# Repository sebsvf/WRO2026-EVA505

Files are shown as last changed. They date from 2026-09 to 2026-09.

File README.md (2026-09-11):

<!--
EVA505 · README principal.
Los cuadros de fotografía ya se renderizan: cada uno utiliza un SVG local.
Para incorporar una foto, cambia únicamente el atributo src del cuadro.
Las rutas propuestas y la lista de imágenes están en docs/IMAGENES_README.md.
-->

<p align="center">
  EVA505 · WRO Future Engineers 2026 · Mecánica R08, visión y control autónomo
</p>

<h1 align="center">EVA505 · Future Engineers 2026</h1>

<p align="center">
  <strong>Diseño mecánico, visión artificial y control embebido en un mismo vehículo.</strong><br>
  Equipo EVA505 · UTEC / IEEE RAS UTEC
</p>

<p align="center">
  <a href="#proyecto">Proyecto</a> ·
  <a href="#arquitectura">Arquitectura</a> ·
  <a href="#mecanica">Mecánica</a> ·
  <a href="#electronica">Electrónica</a> ·
  <a href="#software">Software</a> ·
  <a href="#ejecucion">Ejecución</a> ·
  <a href="#validacion">Validación</a> ·
  <a href="#repositorio">Archivos</a>
</p>

<table>
  <tr>
    <td width="33%" align="center"><strong>R08</strong><br><sub>Revisión mecánica · 4 diseños, 5 piezas</sub></td>
    <td width="34%" align="center"><strong>Raspberry Pi 5 + ESP32</strong><br><sub>Visión, navegación y control de actuadores</sub></td>
    <td width="33%" align="center"><strong>Sin encoder</strong><br><sub>Tracción por PWM · dirección Ackermann</sub></td>
  </tr>
</table>

---

## 01 · El proyecto

**EVA505 es un vehículo autónomo desarrollado para WRO Future Engineers 2026.** Integra un chasis comercial de cuatro ruedas, dirección delantera Ackermann, tracción trasera y soportes diseñados para impresión 3D. La cámara aporta la información visual de la pista; la Raspberry Pi interpreta esa información y el ESP32 ejecuta las órdenes de dirección y tracción.

El repositorio reúne el diseño mecánico, el esquema eléctrico, el firmware, los algoritmos de percepción y navegación, las herramientas de diagnóstico y la evidencia de validación. Su organización permite seguir el recorrido completo desde una pieza CAD hasta una orden enviada al motor.

| Área | Solución de EVA505 |
| :--- | :--- |
| Estructura | Chasis comercial con dos plataformas, portal frontal y rieles de batería R08. |
| Movimiento | Motor DC GA25 para tracción trasera y servo MG996R para dirección. |
| Percepción | Cámara, Picamera2 y OpenCV; análisis de paredes, pilares y marcadores de suelo. |
| Decisión | Control de dirección PD y máquina de estados en Python. |
| Ejecución | ESP32 con PWM, rampas, pulsador START y vigilancia de comandos. |
| Reproducibilidad | Archivos STEP/STL, configuración YAML, pruebas y registros de resultados. |

> **Estado de la revisión:** software validado en PC y firmware compilado. La calibración del vehículo, la validación eléctrica bajo carga y las tandas completas en pista siguen pendientes de registro. El estacionamiento permanece experimental y desactivado por defecto.

### El vehículo en cuatro vistas

<table>
  <tr>
    <td width="50%" align="center" valign="top">
      <!-- FOTO 01 · src sugerido: v-photos/robot-frontal.jpg -->
      Espacio para la vista frontal de EVA505
      <br><strong>01 · Vista frontal</strong><br>
      <sub>Cámara, dirección y despeje de las ruedas delanteras.</sub>
    </td>
    <td width="50%" align="center" valign="top">
      <!-- FOTO 02 · src sugerido: v-photos/robot-superior.jpg -->
      Espacio para la vista superior de EVA505
      <br><strong>02 · Vista superior</strong><br>
      <sub>Distribución de plataformas, electrónica y batería.</sub>
    </td>
  </tr>
  <tr>
    <td width="50%" align="center" valign="top">
      <!-- FOTO 03 · src sugerido: v-photos/robot-lateral.jpg -->
      Espacio para la vista lateral de EVA505
      <br><strong>03 · Vista lateral</strong><br>
      <sub>Separación entre niveles y posición del portal.</sub>
    </td>
    <td width="50%" align="center" valign="top">
      <!-- FOTO 04 · src sugerido: v-photos/robot-trasera.jpg -->
      Espacio para la vista trasera de EVA505
      <br><strong>04 · Vista trasera</strong><br>
      <sub>Tracción, retención de batería y acceso al montaje.</sub>
    </td>
  </tr>
</table>

## 02 · Arquitectura del sistema

El procesamiento se divide entre dos placas. La **Raspberry Pi 5** trabaja con imágenes y toma decisiones; el **ESP32** mantiene el control de los actuadores y supervisa la vigencia de las órdenes recibidas.

<p align="center">
  Cámara a Raspberry Pi 5; comunicación UART bidireccional con ESP32; ESP32 conectado a START, DRV8871 y servo MG996R
</p>

| Capa | Responsabilidad | Resultado |
| :--- | :--- | :--- |
| Captura | Obtener un fotograma reciente y controlar exposición y balance de blancos. | Imagen BGR y referencia temporal. |
| Percepción | Localizar límites de pista, pilares y marcadores mediante HSV y geometría de imagen. | Error lateral, candidatos y confianza. |
| Navegación | Seleccionar el comportamiento y calcular dirección y potencia. | Una orden conjunta de movimiento. |
| Comunicación | Enviar comandos y comprobar telemetría, secuencias y CRC. | Intercambio UART supervisado. |
| Actuación | Aplicar PWM, límites, rampas y condiciones de arranque. | Tracción y dirección dentro de los límites configurados. |

La comunicación funciona a **115 200 baudios**. La telemetría informa del PWM aplicado, el ángulo ordenado y el estado del controlador; no representa mediciones de velocidad ni de posición del servo.

## 03 · Diseño mecánico R08

### Chasis, dirección y tracción

La base comercial conserva su dirección y transmisión. El **GA25** transmite movimiento al tren trasero, mientras el **MG996R** acciona el mecanismo de dirección delantero.

La geometría **Ackermann** hace que la rueda interior gire más que la exterior durante una curva, aproximando sus trayectorias a un centro de giro común. El radio de giro real depende de la distancia entre ejes, la separación de las ruedas y los ángulos alcanzados por el mecanismo; todavía no se publica un valor medido.

Sobre esta base se distribuyen dos plataformas, un portal de cámara y dos rieles para la batería. La división en subconjuntos facilita desmontar componentes y modificar sus soportes conservando las interfaces de fijación.

### Piezas y archivos de fabricación

Las dimensiones exteriores de esta tabla se comprobaron sobre los **STL presentes en el repositorio**. Son cotas de las piezas, no las dimensiones totales del vehículo.

| Pieza | Cantidad | Envolvente nominal, mm | Función | Descargas |
| :--- | :---: | :--- | :--- | :--- |
| Plataforma inferior | 1 | 104 × 84 × 3,2 | Fijación al chasis, electrónica y soporte del nivel superior. | [STL](Mechanics/EVA505_ELECTRONICS_DECK_UNIVERSAL_R08.stl) · [STEP](Mechanics/EVA505_ELECTRONICS_DECK_UNIVERSAL_R08.step) |
| Plataforma superior | 1 | 104 × 84 × 3,2 | Apoyo del case de la Pi y fijación de módulos inferiores. | [STL](Mechanics/EVA505_PI_CASE_DECK_UNIVERSAL_R08.stl) · [STEP](Mechanics/EVA505_PI_CASE_DECK_UNIVERSAL_R08.step) |
| Portal frontal | 1 | ≈ 40,731 × 79 × 94,643 | Soporte elevado e inclinado de la cámara. | [STL](Mechanics/EVA505_FRONT_CAMERA_PORTAL_R08_PROTOTYPE.stl) · [STEP](Mechanics/EVA505_FRONT_CAMERA_PORTAL_R08_PROTOTYPE.step) |
| Riel de batería | 2 | 72 × 14 × 3,2 por unidad | Apoyo y paso de las correas de retención. | [STL](Mechanics/EVA505_BATTERY_STRAP_RAIL_UNIVERSAL_R08_PRINT_2.stl) · [STEP](Mechanics/EVA505_BATTERY_STRAP_RAIL_UNIVERSAL_R08_PRINT_2.step) |

**Cuatro diseños y cinco piezas impresas.** El sufijo `PRINT_2` indica dos unidades del riel. Los STL se interpretan en milímetros y a escala del 100 %.

<table>
  <tr>
    <td width="50%" align="center" valign="top">
      <a href="Mechanics/EVA505_ELECTRONICS_DECK_UNIVERSAL_R08.png">
        Plano de la plataforma inferior de electrónica R08
      </a>
      <br><strong>Plataforma inferior</strong><br><sub>Interfaz con el chasis y distribución de cargas.</sub>
    </td>
    <td width="50%" align="center" valign="top">
      <a href="Mechanics/EVA505_PI_CASE_DECK_UNIVERSAL_R08.png">
        Plano de la plataforma superior para Raspberry Pi R08
      </a>
      <br><strong>Plataforma superior</strong><br><sub>Case de la Raspberry Pi y segundo nivel.</sub>
    </td>
  </tr>
  <tr>
    <td width="50%" align="center" valign="top">
      <a href="Mechanics/EVA505_FRONT_CAMERA_PORTAL_R08_PROTOTYPE.png">
        Plano del portal frontal de cámara R08
      </a>
      <br><strong>Portal frontal</strong><br><sub>Dos apoyos y placa de cámara inclinada.</sub>
    </td>
    <td width="50%" align="center" valign="top">
      <a href="Mechanics/EVA505_BATTERY_STRAP_RAIL_UNIVERSAL_R08_PRINT_2.png">
        Plano del riel de batería R08
      </a>
      <br><strong>Riel de batería</strong><br><sub>Dos copias con retención mediante correas.</sub>
    </td>
  </tr>
</table>

### Interfaces y decisiones de diseño

Las cotas de interfaces que siguen proceden del aporte mecánico R08 del equipo. Los separadores y suplementos indicados como propuesta corresponden al montaje previsto; su ajuste físico todavía debe registrarse.

| Elemento | Cota o solución nominal | Motivo de diseño |
| :--- | :--- | :--- |
| Unión inferior al chasis | Cuatro ranuras de 16 × 10 mm; centros en patrón de 82 × 64 mm. | Admitir pequeñas diferencias de posición de la base comercial. |
| Reparto del apriete | Arandelas con diámetro exterior de al menos 16 mm. | Distribuir la carga sobre las ventanas de fijación. |
| Apilamiento | Patrón de 54 × 44 mm; agujeros de Ø 3,8 mm. | Mantener una interfaz independiente del ajuste al chasis. |
| Separación vertical | Propuesta: cuatro separadores M3 de 35 mm. | Alojar módulos y conectores entre plataformas. |
| Plataforma superior | Contorno desplazado 8 mm hacia atrás; agujeros conservados. | Liberar espacio para el portal sin mover el patrón estructural. |
| Base del portal | Dos fijaciones separadas 65 mm, de Ø 3,8 mm. | Sujetar la cámara con dos apoyos independientes. |
| Interfaz de cámara | Patrón de 21 × 12,5 mm; agujeros de Ø 2,4 mm; inclinación de 15°. | Definir la posición del módulo y orientar la vista hacia la pista. |
| Retención de batería | Dos rieles y una correa por riel. | Permitir su retirada sin desmontar las plataformas. |

El desplazamiento de la plataforma superior ya forma parte de su geometría: el ensamblaje conserva la coincidencia de los agujeros. Los **94,643 mm del portal** describen su altura exterior, no la altura de la lente respecto al suelo.

<details>
<summary><strong>Detalles del montaje y tolerancias</strong></summary>

- **Referencia de ejes:** X longitudinal, frente hacia X negativo; Y transversal y Z vertical.
- **Plataformas:** con separadores de 35 mm y placas de 3,2 mm, la distancia nominal entre sus caras inferiores es 38,2 mm. Los módulos reducen el espacio libre local.
- **Portal:** el aporte R08 describe 3,5 mm nominales de separación con el borde delantero de la plataforma superior. Propone suplementos de 3 mm bajo ambos apoyos cuando la tornillería cercana lo requiera.
- **Batería de referencia:** envolvente objetivo de 90 × 35 × 20 mm, con el lado de 90 mm transversal al vehículo. Esta envolvente no especifica su tensión, capacidad ni química.
- **Rieles:** ranuras de fijación de 10,4 × 4,8 mm, con centros separados 56 mm. La propuesta contempla aproximadamente 1,5 mm de elevación para las correas y 1 mm de material antideslizante.
- **Fabricación:** material, orientación, paredes, relleno y tolerancias de impresión influyen en la rigidez y el ajuste. El repositorio no atribuye una resistencia o masa final a partir del STL.

Las referencias de montaje no sustituyen las medidas del conjunto construido. El despeje de las ruedas, las bieletas, la transmisión y el cableado se evalúa durante todo su recorrido.

</details>

### Del CAD al vehículo

El formato **STL** describe una superficie mediante triángulos y se utiliza en el laminador. **STEP** permite intercambiar geometría para inspección y ensamblaje en CAD. Una conversión desde una malla no recupera automáticamente los croquis ni el historial paramétrico original.

El paquete publicado en `Mechanics/` contiene los cuatro pares STEP/STL y sus planos PNG. Las fuentes generadoras y los informes adicionales citados en el aporte mecánico no están incluidos en esta carpeta.

<table>
  <tr>
    <td width="50%" align="center" valign="top">
      <!-- FOTO 05 · src sugerido: v-photos/direccion-ackermann.jpg -->
      Espacio para el detalle del mecanismo Ackermann
      <br><strong>Dirección y recorrido</strong><br><sub>Servo, brazos y bieletas del chasis.</sub>
    </td>
    <td width="50%" align="center" valign="top">
      <!-- FOTO 06 · src sugerido: v-photos/montaje-r08.jpg -->
      Espacio para el montaje de plataformas, portal y batería
      <br><strong>Integración R08</strong><br><sub>Separadores, fijación del portal y correas.</sub>
    </td>
  </tr>
</table>

## 04 · Electrónica y alimentación

### Componentes principales

| Componente | Cantidad | Función |
| :--- | :---: | :--- |
| Raspberry Pi 5 | 1 | Captura, visión artificial y navegación. |
| ESP32 DevKit V1 | 1 | Control de actuadores, START y supervisión de órdenes. |
| Cámara | 1 | Observación de la pista; captura mediante Picamera2. |
| DRV8871 | 1 | Etapa de potencia para el motor DC mediante IN1/IN2. |
| Motor GA25 | 1 | Tracción del vehículo. |
| Servo MG996R | 1 | Accionamiento de la dirección. |
| Convertidor XL4005 | 2 | Ramas de alimentación para la Pi y el servo. |
| Pulsador START | 1 | Inicio físico y parada local. |
| Batería | 1 | Fuente de energía del sistema. |
| Fusible, interruptor y distribución | 1 conjunto | Corte general, protección y reparto de alimentación. |

### Distribución de energía

El esquema distribuye la batería desde el conector **XT60**, el fusible **F1 de 10 A** y el interruptor general. Desde la línea conmutada se alimentan el DRV8871 y los dos convertidores XL4005.

| Rama del esquema | Destino | Elementos asociados |
| :--- | :--- | :--- |
| Batería conmutada | Alimentación VM del DRV8871 y entradas de los reguladores. | Distribución WAGO y TVS P6KE12A. |
| `+5V1_PI` | Raspberry Pi y VIN del ESP32. | XL4005 n.º 1 y condensador de 470 µF. |
| `+5V_SERVO` | Alimentación del MG996R. | XL4005 n.º 2, 470 µF y 1000 µF. |
| Motor | Salidas del DRV8871 hacia el GA25. | Condensador de 100 nF entre terminales del motor. |
| GND común | Referencia de potencia y señales. | Conexión compartida entre ambas placas y actuadores. |

Las ramas separan la alimentación del servo y de la computadora, manteniendo una referencia de tierra común. Las tensiones, las caídas bajo carga y la capacidad efectiva del montaje todavía no tienen mediciones publicadas.

### Mapa de conexiones

| Señal | Raspberry Pi / periférico | ESP32 | Configuración |
| :--- | :--- | :--- | :--- |
| UART Pi → ESP32 | Pin físico 8, GPIO14 / TX | GPIO16 / RX2 | 115 200 baudios, señales de 3,3 V. |
| UART ESP32 → Pi | Pin físico 10, GPIO15 / RX | GPIO17 / TX2 | Comunicación cruzada TX → RX. |
| Tierra | Pi pin físico 6 y GND de módulos | GND | Referencia común. |
| Motor IN1 | DRV8871 IN1 | GPIO25 | PWM de 20 kHz, canal 0. |
| Motor IN2 | DRV8871 IN2 | GPIO26 | PWM de 20 kHz, canal 1. |
| Dirección | MG996R SIGNAL | GPIO18 | PWM de 50 Hz, canal 2. |
| START | Pulsador hacia GND | GPIO4 | Entrada con pull-up; activo en LOW. |
| Encoder | No instalado | No utilizado | Sin AS5600, ticks ni RPM. |

**La numeración física de la Raspberry Pi es distinta de su numeración GPIO.** El servo utiliza un temporizador separado de los canales del motor.

<details>
<summary><strong>Esquema eléctrico de referencia</strong></summary>

<p align="center">
  <a href="hardware/schematic-reference.png">
    Esquema de alimentación, ESP32, Raspberry Pi, DRV8871, servo y START
  </a>
</p>

**Este esquema conserva el AS5600 en J10 como referencia histórica. El equipo retiró el encoder y esa conexión no forma parte de la versión actual.** El [documento de cableado](hardware/readme.md) recoge la correspondencia operativa con el firmware.

</details>

<table>
  <tr>
    <td width="50%" align="center" valign="top">
      <!-- FOTO 07 · src sugerido: v-photos/electronica-general.jpg -->
      Espacio para la distribución real de la electrónica
      <br><strong>Distribución electrónica</strong><br><sub>Placas, reguladores y organización del cableado.</sub>
    </td>
    <td width="50%" align="center" valign="top">
      <!-- FOTO 08 · src sugerido: v-photos/potencia-y-conexiones.jpg -->
      Espacio para el detalle de las conexiones eléctricas
      <br><strong>Potencia y conexiones</strong><br><sub>Protecciones, UART y conexiones de actuadores.</sub>
    </td>
  </tr>
</table>

## 05 · Percepción, navegación y control

### Raspberry Pi: de la imagen a la trayectoria

El programa obtiene fotogramas recientes y comparte una conversión HSV entre los detectores. La pista se estima a partir de límites y zonas transitables de la imagen. Cuando la perspectiva lo requiere, se utiliza también el perfil de contacto entre pared y suelo.

Los pilares se filtran por color y posición, dando prioridad a los candidatos con mayor proximidad aparente. La dirección se calcula mediante un **control PD con derivada filtrada**, compensación de curvatura y límite de cambio angular.

| Función | Implementación actual |
| :--- | :--- |
| Seguimiento de pista | Error lateral normalizado, confianza y evidencia de paredes. |
| Pilares | Detección de rojo y verde; separación respecto a sus bordes en la imagen. |
| Paso de obstáculos | Estrategia configurada: rojo por la derecha y verde por la izquierda del vehículo. |
| Marcadores de sección | Detección de líneas azules o naranjas, confirmación y antirrebote temporal. |
| Vueltas | Estimación a partir de secciones visuales; configuración inicial de 3 vueltas y 4 secciones por vuelta. |
| Final de recorrido | Aproximación temporal tras el último marcador, pendiente de calibración física. |
| Estacionamiento | Estados experimentales, dos marcadores y maniobra temporal explícita; desactivado. |
| Diagnóstico | Registros JSONL de estados, órdenes, tiempos de procesamiento y motivos de parada. |

La estrategia es reactiva sobre la imagen. No incorpora odometría ni un mapa global; el tiempo de aplicación de una orden no se interpreta como una distancia recorrida.

### Máquina de estados

| Estado | Comportamiento |
| :--- | :--- |
| `INITIALIZATION` | Prepara la ejecución y comprueba las condiciones iniciales. |
| `READY` | Espera una nueva pulsación física de START después de ARM. |
| `FOLLOW_TRACK` | Calcula y aplica seguimiento de pista. |
| `OBSTACLE_AVOID` | Ajusta la trayectoria para rodear el pilar seleccionado. |
| `FINISH_APPROACH` | Ejecuta la aproximación final configurada. |
| `PARKING_*` | Busca, alinea y maniobra cuando el estacionamiento está habilitado. |
| `FINISHED` | Finaliza la ejecución y corta la tracción. |
| `SAFE_STOP` | Mantiene la parada tras un fallo detectado. |

### ESP32: actuación y supervisión

El firmware recibe una orden conjunta de potencia y dirección, aplica límites y genera las señales PWM. La rampa del motor suaviza los cambios de potencia y una pausa de inversión evita pasar directamente de un sentido al contrario.

| Mecanismo | Comportamiento implementado |
| :--- | :--- |
| Arranque físico | HELLO y ARM preparan el controlador; una nueva pulsación de START habilita el movimiento. |
| Parada local | Una segunda pulsación corta la tracción. |
| Vigilancia de movimiento | Sin un DRIVE válido durante 300 ms, el firmware corta y registra un fallo. |
| Integridad de mensajes | CRC-16/CCITT-FALSE, sesión y secuencias para detectar corrupción y rechazar mensajes repetidos. |
| Frescura en la Pi | La telemetría debe avanzar y llegar dentro del plazo configurado de 250 ms. |
| Fallos de percepción | Se rechazan fotogramas repetidos o tardíos; la pérdida de pista reduce la potencia a cero. |
| Recuperación | Una conexión recuperada no reinicia automáticamente el vehículo. |

**STOP coloca IN1 e IN2 a cero:** elimina el accionamiento y deja el motor en rueda libre. No equivale a un frenado mecánico instantáneo.

El protocolo y sus campos se documentan en [PROTOCOLO.md](docs/PROTOCOLO.md). Un mensaje PING no prolonga la vigencia de una orden de movimiento.

### Parámetros de partida

| Parámetro | Valor actual | Interpretación |
| :--- | :--- | :--- |
| Imagen | 640 × 480 px | Resolución configurada. |
| Frecuencia de captura | Objetivo de 25 FPS | No es una medición de rendimiento en la Pi. |
| Potencia de crucero | 0,22 | Fracción PWM; no representa m/s. |
| Límite de potencia | ±0,35 | Límite inicial de puesta en marcha. |
| Servo | Centro 90°; límites 60–120° | Valores de mando provisionales, no ángulos medidos de las ruedas. |
| Tiempo máximo de ejecución | 180 s | Límite local del programa. |
| Estacionamiento | Desactivado | `parking.enabled: false`. |

La configuración principal está en [config.yaml](models/raspberry%20pi%205/config/config.yaml); los límites de actuadores están en [config.h](models/esp32/config.h). Ambos forman parte de una misma configuración del vehículo.

## 06 · Instalación y ejecución

### Desarrollo en PC

El proyecto requiere **Python 3.10 o posterior**. Los comandos siguientes utilizan Python 3.13 en Windows, desde la raíz del repositorio.

```powershell
py -3.13 -m venv .venv
.\.venv\Scripts\python.exe -m pip install -e ".[dev]"

# Comprobar configuración y ejecutar sin abrir hardware.
.\.venv\Scripts\python.exe -m raspberry_pi --check-config
.\.venv\Scripts\python.exe -m raspberry_pi --simulate --frames 150

# Pruebas automatizadas y compilación del firmware.
.\.venv\Scripts\python.exe -m pytest -q
.\.venv\Scripts\pio.exe run
```

La simulación utiliza imágenes sintéticas y un enlace simulado. Permite comprobar la integración del programa sin accionar el robot.

<details>
<summary><strong>Comprobaciones adicionales de desarrollo</strong></summary>

```powershell
.\.venv\Scripts\ruff.exe check models tests scripts
.\.venv\Scripts\ruff.exe format --check models tests scripts

# Compilar el firmware real contra periféricos simulados en Windows.
.\.venv\Scripts\python.exe -m pip install ziglang==0.16.0
.\.venv\Scripts\python.exe scripts/test_firmware.py
```

En Linux, el último script utiliza `g++` cuando está disponible. La compilación para ESP32 se define en [platformio.ini](platformio.ini), con Espressif32 6.12.0 y Arduino ESP32 2.0.17.

</details>

### Raspberry Pi 5

La instalación utiliza **Raspberry Pi OS de 64 bits** y las bibliotecas de cámara de APT:

```bash
sudo apt update
sudo apt install python3-picamera2 python3-opencv python3-numpy \
  python3-yaml python3-serial python3-venv

cd WRO2026-EVA505
python3 -m venv --system-site-packages .venv
source .venv/bin/activate
python -m pip install --no-deps -e .
python -m raspberry_pi --check-config
```

**UART en Pi 5:** el puerto correspondiente a GPIO14/15 debe estar habilitado y verificado. `/dev/serial0` puede corresponder al conector de depuración. Por eso `serial.port` queda sin un valor supuesto.

Con el firmware compatible cargado y el UART del cabezal confirmado:

```bash
# /dev/ttyAMA0 es un ejemplo: usar el dispositivo verificado.
python -m raspberry_pi --port /dev/ttyAMA0 \
  --challenge open --log-jsonl reports/pista-open.jsonl
```

El modo con obstáculos se selecciona con `--challenge obstacle`. El programa prepara cámara y comunicación, arma el controlador y espera **START**.

La [guía de puesta en marcha](docs/PUESTA_EN_MARCHA.md) desarrolla la configuración del UART, la carga de firmware, las pruebas con ruedas suspendidas y la calibración de cámara y actuadores.

### Herramientas incluidas

| Herramienta | Uso |
| :--- | :--- |
| [bench.py](scripts/bench.py) | Pruebas breves de motor y servo, con límites y pulsación START. |
| [vision_probe.py](scripts/vision_probe.py) | Inspección de una imagen y salida anotada. |
| [validate_dataset.py](scripts/validate_dataset.py) | Procesamiento del conjunto de imágenes y generación de resultados. |
| [test_firmware.py](scripts/test_firmware.py) | Ejecución del firmware real con periféricos simulados en el PC. |

## 07 · Validación y resultados

Los siguientes resultados corresponden a la revisión de software del **11 de septiembre de 2026**, documentada en los archivos de `reports/`.

| Comprobación | Resultado registrado | Evidencia |
| :--- | :--- | :--- |
| Python · OpenCV 5.0.0 / NumPy 2.5.3 | **90 pruebas aprobadas** | [Reporte XML](reports/pytest-opencv5.xml) |
| Python · OpenCV 4.12.0 / NumPy 2.2.6 | **90 pruebas aprobadas** | [Reporte XML](reports/pytest-opencv4.xml) |
| Firmware ESP32 · PlatformIO | **Compilación correcta** | [Registro](reports/firmware-build.txt) |
| Firmware con periféricos simulados | **Prueba correcta** | [Registro](reports/firmware-native.txt) |
| Análisis estático y formato | **Comprobaciones correctas** | [Registro](reports/static-check.txt) |
| Simulación del programa | **Inicio, ejecución y cierre comprobados** | [Registro](reports/simulation-check.txt) |
| Conjunto de imágenes | **184/184 procesadas sin excepciones** | [Resultados JSON](reports/vision_validation.json) |

La compilación registrada utiliza **21 864 bytes de RAM estática** y **284 549 bytes de flash**. Estas cifras describen el binario compilado, no el consumo máximo de memoria durante una carrera.

### Evidencia visual

<p align="center">
  <a href="reports/vision_validation.jpg">
    Muestra de imágenes del dataset con detecciones y anotaciones del sistema de visión
  </a>
  <br><sub>Muestra real generada por las herramientas de validación del repositorio.</sub>
</p>

| Observación del conjunto de imágenes | Resultado |
| :--- | ---: |
| Imágenes sobre el umbral de confianza de pista | 115 |
| Imágenes por debajo del umbral | 69 |
| Imágenes con al menos un candidato a pilar | 123 |
| Tiempo mediano de procesamiento en el PC de desarrollo | ≈ 3,36 ms |
| Percentil 95 de procesamiento en ese PC | ≈ 6,73 ms |

**La confianza del detector no es una precisión medida.** Estos resultados describen fotos estáticas y tiempos del PC de desarrollo; no demuestran vueltas completadas ni rendimiento en Raspberry Pi 5. Las etiquetas de los dos grupos contienen clases no equivalentes, cajas y polígonos, por lo que no se publica una métrica global de precisión o recall.

<details>
<summary><strong>Alcance de las pruebas y validación física pendiente</strong></summary>

Las pruebas automatizadas cubren corrupción de mensajes, secuencias repetidas, desbordamiento de recepción, expiración de comandos, arranque físico, límites, rampas, inversión, pérdida de cámara, fotogramas tardíos y casos de percepción y navegación.

La evidencia física pendiente comprende alimentación bajo carga, funcionamiento del UART en la Pi, centro y límites del servo, respuesta del motor con distintas cargas de batería, vista de cámara definitiva, recorridos completos y estacionamiento.

La receta de [integración continua](.github/workflows/ci.yml) está incluida. Los resultados de esta tabla proceden de ejecuciones locales; no se presenta una ejecución en GitHub como realizada.

</details>

### Registro audiovisual de pista

<table>
  <tr>
    <td width="50%" align="center" valign="top">
      <!-- FOTO 09 · src sugerido: v-photos/pista-open.jpg · Puede envolverse en un enlace al vídeo. -->
      Espacio para la portada del vídeo del recorrido abierto
      <br><strong>Recorrido abierto</strong><br><sub>Registro audiovisual pendiente de incorporar.</sub>
    </td>
    <td width="50%" align="center" valign="top">
      <!-- FOTO 10 · src sugerido: v-photos/pista-obstacle.jpg · Puede envolverse en un enlace al vídeo. -->
      Espacio para la portada del vídeo del recorrido con obstáculos
      <br><strong>Recorrido con obstáculos</strong><br><sub>Registro audiovisual pendiente de incorporar.</sub>
    </td>
  </tr>
</table>

## 08 · Organización del repositorio

```text
WRO2026-EVA505/
├── README.md                         # Presentación y documentación principal
├── Mechanics/                        # Cuatro diseños R08: STEP, STL y planos PNG
├── hardware/                         # Cableado y esquema de referencia
├── models/
│   ├── esp32/                        # Firmware, motor, servo y protocolo
│   └── raspberry pi 5/               # Aplicación Python y configuración
│       ├── camera/                   # Captura y calibración
│       ├── communication/            # Enlace UART y protocolo
│       ├── config/                   # YAML y validación de parámetros
│       ├── control/                  # Órdenes y controlador de dirección
│       ├── navigation/               # Movimiento y control
│       ├── state machine/            # Estados y transiciones
│       └── vision/                   # Pista, pilares y marcadores
├── scripts/                          # Banco de pruebas y herramientas de visión
├── tests/                            # Pruebas Python y firmware para host
│   └── datastets/obstacles/           # Imágenes y etiquetas; nombre original
├── reports/                          # Evidencia de validación
├── docs/                             # Guías técnicas y recursos del README
│   └── media/                        # Portada, diagrama y cuadros de imagen
├── t-photos/                         # Ubicación prevista para fotografías del equipo
├── v-photos/                         # Ubicación prevista para fotografías del vehículo
├── videos/                           # Ubicación prevista para registros de pista
├── platformio.ini                    # Compilación ESP32
└── pyproject.toml                    # Instalación y herramientas de Python
```

Las carpetas originales con espacios se conservan. La instalación expone el paquete `raspberry_pi` y su máquina de estados, sin modificaciones manuales de `sys.path`.

### Documentación complementaria

| Documento | Contenido |
| :--- | :--- |
| [Puesta en marcha](docs/PUESTA_EN_MARCHA.md) | Instalación, UART, firmware, calibración y pruebas de pista. |
| [Protocolo C1 / T1](docs/PROTOCOLO.md) | Formato de mensajes, CRC, sesiones, comandos y telemetría. |
| [Cableado](hardware/readme.md) | Pines, funcionamiento del DRV8871 y versión sin encoder. |
| [Revisión y mejoras](docs/REVISION_Y_MEJORAS.md) | Cambios de software, resultados y alcance de la validación. |
| [Inventario de fuentes](reports/source_inventory.json) | Trazabilidad de los 35 archivos originales revisados. |
| [Imágenes del README](docs/IMAGENES_README.md) | Ubicación de los cuadros y sustitución de fotografías. |

## 09 · Equipo EVA505

**EVA505 · UTEC / IEEE RAS UTEC**

El proyecto reúne diseño mecánico, integración electrónica y programación de sistemas autónomos. Este repositorio documenta las decisiones de construcción y la evidencia disponible de cada revisión.

<table>
  <tr>
    <td align="center">
      <!-- FOTO 11 · src sugerido: t-photos/equipo-eva505.jpg -->
      Espacio para la fotografía del equipo EVA505
      <br><strong>El equipo detrás de EVA505</strong><br><sub>Diseño · Integración · Programación · Pruebas</sub>
    </td>
  </tr>
</table>

---

<p align="center">
  <strong>EVA505 · Mecánica R08 · Software 0.2.0</strong><br>
  <sub>Documentación técnica del vehículo y su proceso de desarrollo.</sub><br><br>
  <a href="#inicio">Volver al inicio ↑</a>
</p>

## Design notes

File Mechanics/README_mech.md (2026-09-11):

# EVA-505 | Chasis y diseño mecánico

EVA-505 utiliza un **chasis comercial de cuatro ruedas, dirección Ackermann y tracción trasera**. Sobre esta base se incorporan las piezas impresas de la revisión **R08**, destinadas a sostener la electrónica, posicionar la cámara y sujetar la batería.

El trabajo mecánico se centra en adaptar los soportes al espacio disponible, conservar el movimiento del chasis y facilitar el montaje y mantenimiento del robot.

## Chasis y movimiento

El chasis conserva su estructura y transmisión comerciales. La dirección delantera se acciona mediante un **servomotor MG996R**, que mueve el mecanismo de dirección. La geometría Ackermann permite que la rueda interior gire más que la exterior al tomar una curva, aproximando el movimiento de ambas a un mismo centro de giro.

La tracción se transmite a las ruedas traseras mediante el motor y el conjunto de engranajes del chasis. Los soportes añadidos deben dejar libres las ruedas, las articulaciones de dirección y la transmisión durante todo su recorrido.

Las placas frontal y trasera sirven como superficies de fijación. Se aprovechan sus puntos de montaje y las ranuras de las piezas impresas para ajustar la posición de los soportes.

## Distribución de las piezas

La zona frontal y central utiliza **dos plataformas superpuestas**. La inferior organiza los módulos electrónicos; la superior sostiene el case de la Raspberry Pi 5 y permite fijar módulos auxiliares por debajo. Los separadores mantienen la distancia entre niveles y dejan espacio para acceder a los componentes.

El **portal de cámara** se coloca en el frente para mantener la cámara orientada hacia la pista. Su estructura une dos apoyos laterales y una placa superior inclinada, buscando una posición estable durante el movimiento.

En la parte trasera se colocan **dos rieles longitudinales para la batería**. La batería se orienta transversalmente, con su dimensión de **90 mm de lado a lado del vehículo**, y se sujeta con tiras y material antideslizante.

## Piezas impresas R08

| Pieza | Cantidad | Función mecánica |
|---|---:|---|
| Plataforma inferior de electrónica | 1 | Une la estructura de soportes al chasis y proporciona ranuras para fijar los módulos. |
| Plataforma superior para el case de la Pi | 1 | Sostiene el case y permite montar componentes bajo la plataforma. |
| Portal frontal de cámara | 1 | Define la posición y orientación de la cámara respecto al chasis. |
| Riel de sujeción de batería | 2 | Proporciona apoyos y pasos para las tiras de retención. |

El conjunto comprende **cuatro diseños y cinco piezas impresas**.

### Archivos de las piezas

- `EVA505_ELECTRONICS_DECK_UNIVERSAL_R08.stl`
- `EVA505_PI_CASE_DECK_UNIVERSAL_R08.stl`
- `EVA505_FRONT_CAMERA_PORTAL_R08_PROTOTYPE.stl`
- `EVA505_BATTERY_STRAP_RAIL_UNIVERSAL_R08_PRINT_2.stl` — imprimir dos unidades.

Los archivos **STL** contienen las geometrías para impresión 3D. Las versiones **STEP**, cuando se incorporan al repositorio, permiten revisar las piezas como sólidos en programas CAD como Onshape.

## Criterios de montaje

El montaje propuesto une las plataformas con **cuatro separadores M3 de 35 mm**, distribuidos en un patrón de **54 × 44 mm**. La plataforma superior tiene el contorno desplazado **8 mm hacia atrás**, dejando espacio para los montantes del portal frontal.

La torre utiliza dos fijaciones independientes. La revisión de montaje propone **separadores de 3 mm bajo sus anclajes** para evitar interferencias con las arandelas anchas del chasis. Esta separación debe comprobarse con la tornillería utilizada.

El case debe apoyarse sin descansar sobre las cabezas de los tornillos y conservar sus entradas de ventilación. Bajo los rieles se deja espacio para pasar las tiras de la batería; sobre ellos se coloca material antideslizante. Las fijaciones deben impedir desplazamientos sin deformar las piezas ni la batería.

La comprobación final se realiza sobre el robot físico: dirección y transmisión libres, batería firme, cámara estable y soportes accesibles. Las cotas del CAD sirven como referencia y se contrastan con las piezas impresas y el chasis real.

## Galería del proyecto

<table>
  <tr>
    <td width="50%" align="center" valign="middle">
      Fotografía 1 del proyecto EVA-505
      <br />
      <sub>Registro del proyecto · 01</sub>
    </td>
    <td width="50%" align="center" valign="middle">
      Fotografía 2 del proyecto EVA-505
      <br />
      <sub>Registro del proyecto · 02</sub>
    </td>
  </tr>
  <tr>
    <td width="50%" align="center">
      <br /><br />
      <strong>Vista superior del chasis</strong>
      <br />
      <sub>Espacio para añadir una fotografía</sub>
      <br /><br />
    </td>
    <td width="50%" align="center">
      <br /><br />
      <strong>Plataformas y separadores</strong>
      <br />
      <sub>Espacio para añadir una fotografía</sub>
      <br /><br />
    </td>
  </tr>
  <tr>
    <td width="50%" align="center">
      <br /><br />
      <strong>Portal frontal de cámara</strong>
      <br />
      <sub>Espacio para añadir una fotografía</sub>
      <br /><br />
    </td>
    <td width="50%" align="center">
      <br /><br />
      <strong>Rieles y sujeción de batería</strong>
      <br />
      <sub>Espacio para añadir una fotografía</sub>
      <br /><br />
    </td>
  </tr>
</table>

<!-- Para añadir fotografías, sustituye el contenido del espacio correspondiente por:
<img src="URL_DE_LA_FOTO" width="100%" alt="Descripción de la fotografía" />
<br />
<sub>Pie de foto</sub>
Para ampliar la galería, duplica una fila <tr> completa con sus dos celdas <td>.
-->

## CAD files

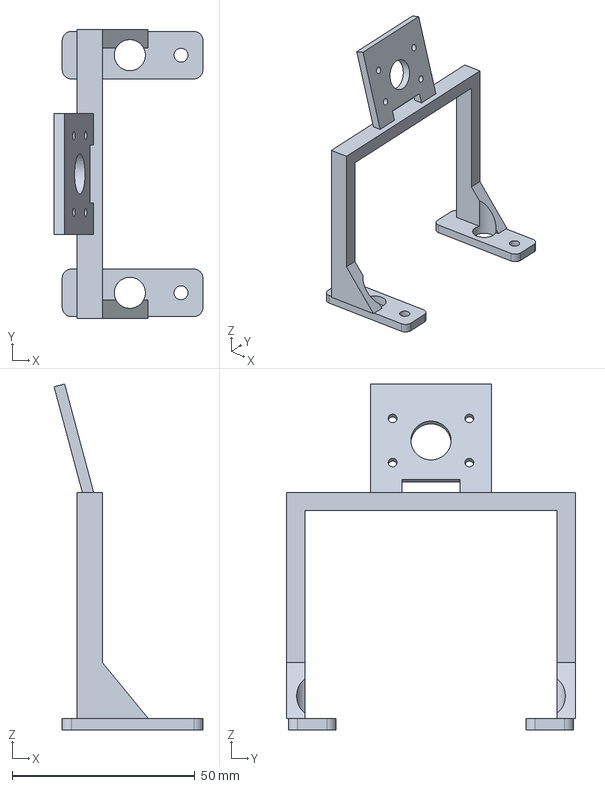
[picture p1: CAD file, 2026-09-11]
Mechanics/EVA505_FRONT_CAMERA_PORTAL_R08_PROTOTYPE.step
40.7 x 79.0 x 94.6 mm

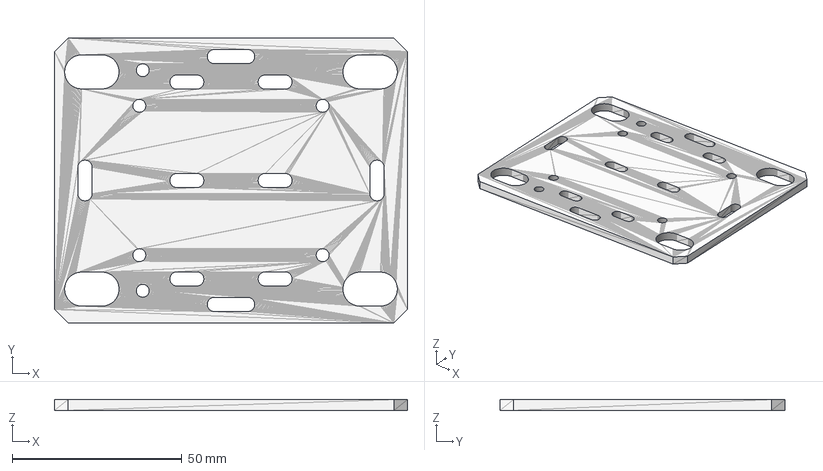
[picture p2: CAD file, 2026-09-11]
Mechanics/EVA505_ELECTRONICS_DECK_UNIVERSAL_R08.step
104.0 x 84.0 x 3.20 mm

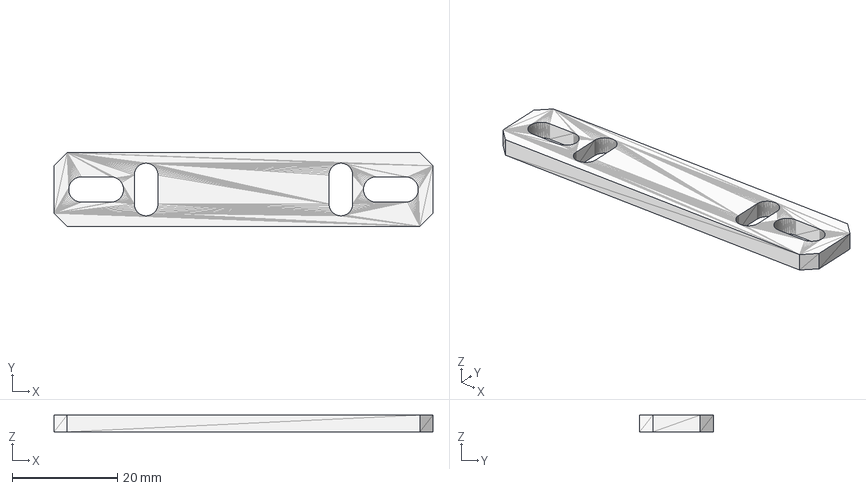
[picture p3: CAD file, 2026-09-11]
Mechanics/EVA505_BATTERY_STRAP_RAIL_UNIVERSAL_R08_PRINT_2.step
72.0 x 14.0 x 3.20 mm

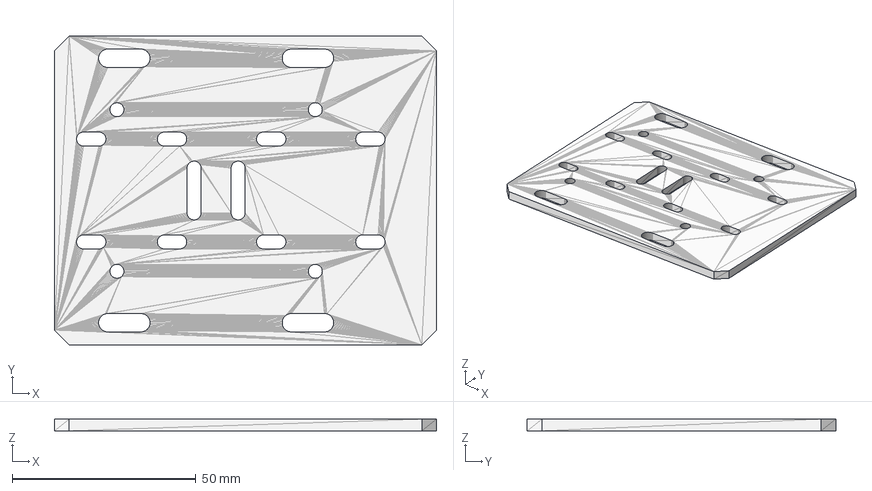
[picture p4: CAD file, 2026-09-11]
Mechanics/EVA505_PI_CASE_DECK_UNIVERSAL_R08.step
104.0 x 84.0 x 3.20 mm

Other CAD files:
Mechanics/EVA505_BATTERY_STRAP_RAIL_UNIVERSAL_R08_PRINT_2.stl
Mechanics/EVA505_ELECTRONICS_DECK_UNIVERSAL_R08.stl
Mechanics/EVA505_FRONT_CAMERA_PORTAL_R08_PROTOTYPE.stl
Mechanics/EVA505_PI_CASE_DECK_UNIVERSAL_R08.stl

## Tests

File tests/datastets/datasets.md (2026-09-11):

datasets from: https://universe.roboflow.com/tfliteintothedeep/wro-blocks/dataset/3
               https://universe.roboflow.com/wro-future-engineers/wro-ikvrj

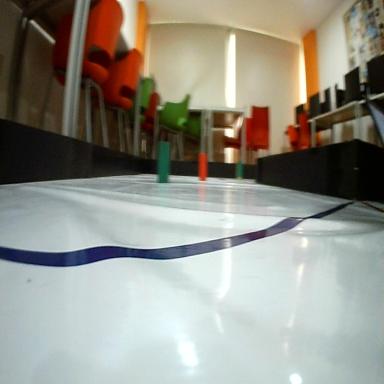
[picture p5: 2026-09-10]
tests/datastets/obstacles/images 1/WIN_20260108_15_36_00_Pro-2-_jpg.rf.017c9e504754a746ed2efdf418440220.jpg

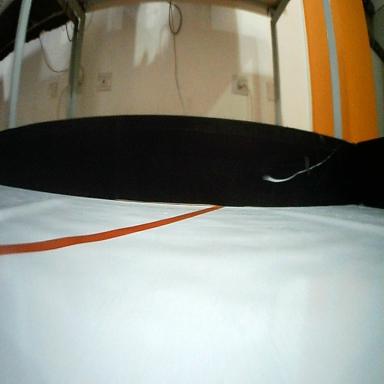
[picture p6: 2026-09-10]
tests/datastets/obstacles/images 1/WIN_20260108_15_31_58_Pro_jpg.rf.e06d18cb7c410cf68ff52b46b838ab88.jpg

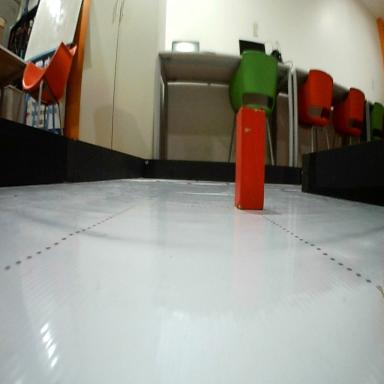
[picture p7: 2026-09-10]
tests/datastets/obstacles/images 1/WIN_20260108_15_33_17_Pro-2-_jpg.rf.ee169d709c49afb46dbfc99f3cd494a5.jpg

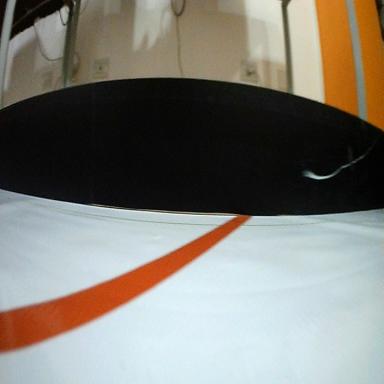
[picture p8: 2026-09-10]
tests/datastets/obstacles/images 1/WIN_20260108_15_31_50_Pro_jpg.rf.68d1b5565724bd7de957eacdac595c3b.jpg

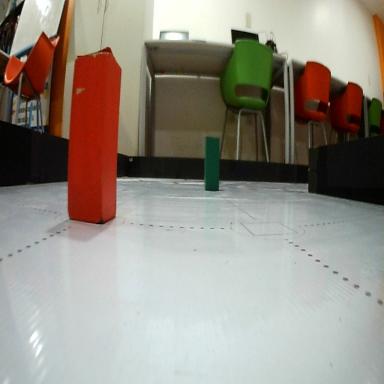
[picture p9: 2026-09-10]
tests/datastets/obstacles/images 1/WIN_20260108_15_33_44_Pro_jpg.rf.0012f757b01c841fbc9f7811a1003059.jpg

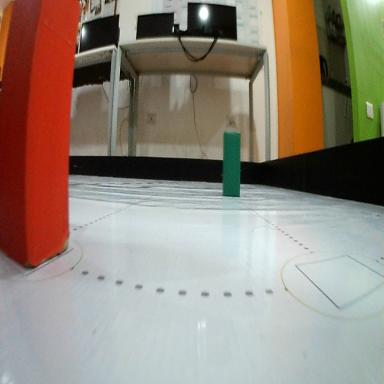
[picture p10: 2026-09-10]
tests/datastets/obstacles/images 1/WIN_20260108_15_31_13_Pro_jpg.rf.f5b023baa02885500520db16535ce3d6.jpg

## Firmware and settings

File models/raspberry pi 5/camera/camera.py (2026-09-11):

import argparse
import logging
import math
import time

import numpy as np

try:
    from picamera2 import Picamera2
except ImportError:
    Picamera2 = None


logger = logging.getLogger("camera")


class CameraFault(Exception):
    """Error de inicio, captura o comunicación con la cámara."""


class Camera:
    def __init__(
        self,
        resolution=(640, 480),
        target_fps=25,
        stale_frame_timeout_s=1.0,
        simulated=False,
    ):
        self.resolution = tuple(resolution)
        self.target_fps = float(target_fps)
        self.stale_frame_timeout_s = float(stale_frame_timeout_s)

        if len(self.resolution) != 2 or any(
            isinstance(v, bool) or not isinstance(v, int) or v <= 0
            for v in self.resolution
        ):
            raise ValueError(
                "resolution debe contener dos enteros positivos"
            )

        for value in (self.target_fps, self.stale_frame_timeout_s):
            if not math.isfinite(value) or value <= 0:
                raise ValueError(
                    "FPS y timeout deben ser positivos y finitos"
                )

        self._simulated = bool(simulated)
        self._picam2 = None
        self._started = False
        self._faulted = False
        self._last_frame_ts = None
        self._last_sensor_timestamp = None
        self.analogue_gain = None

    @property
    def simulated(self):
        return self._simulated

    def _require_started(self):
        if not self._started:
            raise CameraFault(
                "Primero debes llamar a camera.start()"
            )

        if self._faulted:
            raise CameraFault(
                "La cámara falló; llama a stop() y start() "
                "para reiniciarla"
            )

    def _mark_fault(self):
        self._faulted = True
        self._last_frame_ts = None

    def start(self):
        if self._started:
            self._require_started()
            return

        self._faulted = False
        self._last_frame_ts = None
        self._last_sensor_timestamp = None
        self.analogue_gain = None

        if self._simulated:
            self._started = True
            logger.warning(
                "Modo simulado: se entregarán imágenes negras. "
                "No se utilizará una cámara física."
            )
            return

        if Picamera2 is None:
            raise CameraFault(
                "Picamera2 no está disponible en este Python. "
                "En Windows utiliza Camera(simulated=True). "
                "Para captura real ejecuta el programa en la Raspberry "
                "con Picamera2 instalado."
            )

        cam = None

        try:
            cam = Picamera2()

            config = cam.create_video_configuration(
                main={
                    "size": self.resolution,
                    # En Picamera2, RGB888 entrega bytes BGR.
                    "format": "RGB888",
                },
                controls={
                    "FrameRate": self.target_fps,
                },
                queue=False,
            )

            cam.configure(config)
            cam.start()

        except Exception as exc:
            if cam is not None:
                try:
                    cam.close()
                except Exception:
                    logger.exception(
                        "No se pudo liberar la cámara tras el fallo"
                    )

            self._mark_fault()
            raise CameraFault(
                f"No se pudo iniciar la cámara: {exc}"
            ) from exc

        self._picam2 = cam
        self._started = True

        logger.info(
            "Cámara iniciada: %sx%s, objetivo %.1f FPS",
            *self.resolution,
            self.target_fps,
        )

    def capture_metadata(self):
        """Lee metadatos con espera limitada."""
        self._require_started()

        if self._simulated:
            return {}

        try:
            job = self._picam2.capture_metadata(wait=False)
            return job.get_result(
                timeout=self.stale_frame_timeout_s
            )

        except Exception as exc:
            self._mark_fault()
            raise CameraFault(
                f"No se pudieron obtener metadatos: {exc}"
            ) from exc

    def _apply_controls(self, controls):
        self._require_started()

        if self._simulated:
            return

        try:
            self._picam2.set_controls(controls)

        except Exception as exc:
            self._mark_fault()
            raise CameraFault(
                f"No se pudieron aplicar los controles: {exc}"
            ) from exc

    def set_auto_controls(self):
        """Activa exposición y balance de blancos automáticos."""
        self._apply_controls({
            "AeEnable": True,
            "AwbEnable": True,
        })

        self.analogue_gain = None

    def set_manual_controls(
        self,
        exposure_us=None,
        awb_gains=None,
        analogue_gain=None,
    ):
        """
        Solicita controles manuales.

        Exposición y ganancia analógica deben proporcionarse juntas.
        El balance de blancos puede ajustarse independientemente.
        """
        self._require_started()
        controls = {}

        if exposure_us is not None or analogue_gain is not None:
            if exposure_us is None or analogue_gain is None:
                raise ValueError(
                    "Proporciona exposure_us y analogue_gain juntos"
                )

            exposure = float(exposure_us)
            gain = float(analogue_gain)

            if (
                not math.isfinite(exposure)
                or exposure < 1
                or not math.isfinite(gain)
                or gain <= 0
            ):
                raise ValueError(
                    "Exposición o ganancia inválidas"
                )

            controls.update({
                "AeEnable": False,
                "ExposureTime": int(exposure),
                "AnalogueGain": gain,
            })

        if awb_gains is not None:
            gains = tuple(float(v) for v in awb_gains)

            if len(gains) != 2 or any(
                not math.isfinite(v) or v <= 0
                for v in gains
            ):
                raise ValueError(
                    "awb_gains debe contener dos valores positivos"
                )

            controls.update({
                "AwbEnable": False,
                "ColourGains": gains,
            })

        if not controls:
            return

        self._apply_controls(controls)

        if self._simulated:
            logger.info(
                "Controles validados, pero no aplicados: modo simulado"
            )
            return

        if analogue_gain is not None:
            self.analogue_gain = float(analogue_gain)

        logger.info(
            "Controles manuales solicitados: %s",
            controls,
        )

    def capture_frame(self) -> np.ndarray:
        """
        Devuelve un frame BGR uint8.

        En modo real comprueba que el SensorTimestamp avance.
        En modo simulado devuelve una imagen negra.
        """
        self._require_started()

        try:
            if self._simulated:
                width, height = self.resolution
                frame = np.zeros(
                    (height, width, 3),
                    dtype=np.uint8,
                )

            else:
                job = self._picam2.capture_request(wait=False)
                request = job.get_result(
                    timeout=self.stale_frame_timeout_s
                )

                try:
                    metadata = request.get_metadata()
                    stamp = metadata.get("SensorTimestamp")

                    if (
                        isinstance(stamp, bool)
                        or not isinstance(stamp, (int, np.integer))
                        or stamp <= 0
                    ):
                        raise CameraFault(
                            "Fotograma sin SensorTimestamp válido"
                        )

                    if (
                        self._last_sensor_timestamp is not None
                        and stamp <= self._last_sensor_timestamp
                    ):
                        raise CameraFault(
                            "Fotograma repetido o fuera de orden"
                        )

                    # Copiar antes de liberar el buffer de la cámara.
                    frame = request.make_array("main").copy()

                finally:
                    request.release()

            if (
                not isinstance(frame, np.ndarray)
                or frame.dtype != np.uint8
                or frame.ndim != 3
                or frame.shape[2] != 3
                or frame.size == 0
            ):
                raise CameraFault(
                    "La cámara entregó un frame inválido"
                )

            if not self._simulated:
                self._last_sensor_timestamp = int(stamp)

            self._last_frame_ts = time.monotonic()
            return frame

        except Exception as exc:
            # Exigir reinicio evita acumular capturas tras un timeout.
            self._mark_fault()
            raise CameraFault(
                f"Captura inválida o timeout: {exc}"
            ) from exc

    def is_healthy(self) -> bool:
        """Indica si se obtuvo un frame recientemente y sin fallos."""
        return (
            self._started
            and not self._faulted
            and self._last_frame_ts is not None
            and (
                time.monotonic() - self._last_frame_ts
                < self.stale_frame_timeout_s
            )
        )

    def stop(self):
        """Detiene y libera la cámara."""
        cam = self._picam2

        self._picam2 = None
        self._started = False
        self._last_frame_ts = None
        self._last_sensor_timestamp = None
        self.analogue_gain = None

        if cam is not None:
            try:
                cam.stop()
            finally:
                cam.close()


def main():
    """
    Prueba independiente.

    Windows:
        python camera.py

    Raspberry con cámara física:
        python camera.py --real
    """
    parser = argparse.ArgumentParser(
        description="Prueba de captura simulada o real"
    )
    parser.add_argument(
        "--real",
        action="store_true",
        help="Usar la cámara física mediante Picamera2",
    )
    args = parser.parse_args()

    logging.basicConfig(
        level=logging.INFO,
        format="%(levelname)s: %(message)s",
    )

    camera = Camera(simulated=not args.real)

    try:
        camera.start()

        for index in range(3):
            frame = camera.capture_frame()

            print(
                f"Frame {index + 1}: "
                f"dimensiones={frame.shape}, "
                f"tipo={frame.dtype}, "
                f"saludable={camera.is_healthy()}"
            )

            # Solo pausa la prueba; no forma parte del controlador.
            time.sleep(0.1)

        if camera.simulated:
            print(
                "Prueba simulada completada. "
                "Las imágenes son negras; no se probó una cámara física."
            )
        else:
            print("Prueba de captura real completada.")

        return 0

    except CameraFault as exc:
        logger.error("%s", exc)
        return 1

    finally:
        camera.stop()


if __name__ == "__main__":
    raise SystemExit(main())

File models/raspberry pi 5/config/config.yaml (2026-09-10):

# Global configuration for the Raspberry Pi 5 software stack.
# All hardware-dependent values are grouped here so nothing is hard-coded
# inside the application modules. Values marked TODO must be confirmed
# against the physical robot before competition.

camera:
  resolution: [640, 480]
  target_fps: 25
  # Locked exposure/white balance values are written here by
  # camera/calibration.py after the on-site calibration routine.
  exposure_us: null          # TODO: set after calibration (auto-exposure disabled in competition)
  awb_gains: null            # TODO: set after calibration [red_gain, blue_gain]

roi:
  # Lane ROI: lower portion of the frame, used for lane_error / curvature.
  lane_roi_y_range: [0.55, 1.0]   # fraction of frame height [top, bottom]
  # Pillar ROI: wider/upper region, used for early pillar detection.
  pillar_roi_y_range: [0.30, 0.85]

hsv_thresholds:
  # TODO: recalibrate on the actual competition mat/lighting using
  # vision/hsv_config.py's interactive tuning helper before every event.
  lane_boundary:
    lower: [0, 0, 0]
    upper: [180, 60, 60]
  pillar_red:
    lower: [0, 120, 70]
    upper: [10, 255, 255]
  pillar_red_high:      # red wraps around hue 0/180 in OpenCV's HSV space
    lower: [170, 120, 70]
    upper: [180, 255, 255]
  pillar_green:
    lower: [40, 70, 40]
    upper: [85, 255, 200]
  parking_marker:
    lower: [135, 70, 40]     
    upper: [175, 255, 180]

control:
  steering:
    kp: 0.45          # TODO: tune experimentally
    kd: 0.12          # TODO: tune experimentally
    curvature_gain: 0.30
    max_angle_deg: 30      # +/- from center, mechanical limit from Table 2
    center_deg: 90
  pillar_offset:
    bias_deg: 8         # additional steering bias while a pillar is being passed
    ramp_step_deg: 1.5  # per-frame ramp rate back to center after clearing

fsm:
  min_confidence: 0.55
  lost_lane_stop_timeout_s: 1.0
  laps_required: 3
  corner_sections_per_lap: 4

serial:
  port: /dev/serial0     # TODO: confirm against final GPIO UART assignment
  baudrate: 115200
  read_timeout_s: 0.05
  heartbeat_period_s: 0.1
  watchdog_reply_timeout_s: 0.5

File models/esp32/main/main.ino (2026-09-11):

#include "../config.h"
#include "../motor/motor_control.h"
#include "../servo/servo_control.h"
#include "../encoder/encoder.h"

static unsigned long _last_command_ms = 0;
static unsigned long _last_pid_update_ms = 0;
static unsigned long _last_telemetry_ms = 0;
static bool _parking_mode = false;

static String _rx_buffer = "";

void setup() {
  Serial.begin(UART_BAUDRATE, SERIAL_8N1, UART_RX_PIN, UART_TX_PIN);

  motor_init();
  servo_init();
  encoder_init();

  _last_command_ms = millis();
  Serial.println("STATUS:OK");
}

void loop() {
  _read_uart();
  _check_watchdog();

  unsigned long now = millis();

  // Velocity PID at its own fixed rate, independent of UART traffic.
  unsigned long pid_period_ms = 1000UL / VELOCITY_PID_FREQ_HZ;
  if (now - _last_pid_update_ms >= pid_period_ms) {
    motor_update_pid();
    _last_pid_update_ms = now;
  }

  // Telemetry at 20 Hz - enough for the Pi's watchdog / logging
  // without flooding the link.
  if (now - _last_telemetry_ms >= 50) {
    Serial.print("ENC:");
    Serial.println(encoder_get_ticks());
    _last_telemetry_ms = now;
  }
}

static void _read_uart() {
  while (Serial.available() > 0) {
    char c = (char)Serial.read();
    if (c == '\n') {
      _handle_line(_rx_buffer);
      _rx_buffer = "";
    } else if (c != '\r') {
      _rx_buffer += c;
    }
  }
}

static void _handle_line(const String &line) {
  _last_command_ms = millis();

  if (line.startsWith("SET_SPEED:")) {
    float mm_s = line.substring(String("SET_SPEED:").length()).toFloat();
    float limit = _parking_mode ? PARK_MAX_SPEED_MM_S : MAX_SPEED_MM_S;
    mm_s = constrain(mm_s, -limit, limit);
    motor_set_target_speed_mm_s(mm_s);

  } else if (line.startsWith("SET_STEERING:")) {
    float deg = line.substring(String("SET_STEERING:").length()).toFloat();
    servo_set_angle_deg(deg);

  } else if (line == "STOP") {
    motor_stop();

  } else if (line == "MODE:PARK") {
    _parking_mode = true;

  } else if (line == "MODE:DRIVE") {
    _parking_mode = false;

  } else if (line == "PING") {
    Serial.println("PONG");

  } else {
  
    Serial.println("STATUS:FAULT");
  }
}

static void _check_watchdog() {
  if (millis() - _last_command_ms > UART_WATCHDOG_TIMEOUT_MS) {
    // Fail-safe: stop independently of the Raspberry Pi's state.
    // This is the core safety guarantee described in Sec 4.10 of the
    // engineering journal -- it must not depend on receiving a STOP
    // command, since the whole point is handling the Pi going silent.
    motor_stop();
  }
}

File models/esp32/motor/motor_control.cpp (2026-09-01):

#include "motor_control.h"
#include "../config.h"
#include "../encoder/encoder.h"

static float _target_speed_mm_s = 0.0f;
static float _current_speed_mm_s = 0.0f;

// PID internal state
static float _integral = 0.0f;
static float _prev_error = 0.0f;
static unsigned long _last_update_ms = 0;

void motor_init() {
  pinMode(MOTOR_DIR_PIN, OUTPUT);
  ledcSetup(MOTOR_PWM_CHANNEL, MOTOR_PWM_FREQ_HZ, MOTOR_PWM_RESOLUTION_BITS);
  ledcAttachPin(MOTOR_PWM_PIN, MOTOR_PWM_CHANNEL);
  motor_stop();
}

void motor_set_raw_pwm(int pwm) {
  int max_duty = (1 << MOTOR_PWM_RESOLUTION_BITS) - 1;
  pwm = constrain(pwm, -max_duty, max_duty);

  digitalWrite(MOTOR_DIR_PIN, pwm >= 0 ? HIGH : LOW);
  ledcWrite(MOTOR_PWM_CHANNEL, abs(pwm));
}

void motor_stop() {
  _target_speed_mm_s = 0.0f;
  _integral = 0.0f;
  motor_set_raw_pwm(0);
}

void motor_set_target_speed_mm_s(float target_mm_s) {
  _target_speed_mm_s = constrain(target_mm_s, -MAX_SPEED_MM_S, MAX_SPEED_MM_S);
}

float motor_get_current_speed_mm_s() {
  return _current_speed_mm_s;
}

// Called at VELOCITY_PID_FREQ_HZ (100 Hz) from main.ino's timer loop.
void motor_update_pid() {
  unsigned long now = millis();
  unsigned long dt_ms = (_last_update_ms == 0) ? 0 : (now - _last_update_ms);
  _last_update_ms = now;

  float rpm = encoder_get_rpm(dt_ms > 0 ? dt_ms : 1);
  // v = rpm * 2*pi*r / 60  (Engineering Diary Section 1.4)
  _current_speed_mm_s = rpm * 2.0f * PI * WHEEL_RADIUS_MM / 60.0f;

  float error = _target_speed_mm_s - _current_speed_mm_s;

  float dt_s = dt_ms / 1000.0f;
  if (dt_s > 0) {
    _integral += error * dt_s;
    // Basic anti-windup clamp -- tune alongside VELOCITY_PID_KI.
    _integral = constrain(_integral, -500.0f, 500.0f);
  }
  float derivative = (dt_s > 0) ? (error - _prev_error) / dt_s : 0.0f;
  _prev_error = error;

  float output = VELOCITY_PID_KP * error
               + VELOCITY_PID_KI * _integral
               + VELOCITY_PID_KD * derivative;

  int max_duty = (1 << MOTOR_PWM_RESOLUTION_BITS) - 1;
  int pwm = (int)constrain(output, (float)-max_duty, (float)max_duty);
  motor_set_raw_pwm(pwm);
}

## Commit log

2026-09-01 esp32 code
2026-09-01 include tests -servo -motor -encoder -camera
2026-09-10 Integrate AS5600 sensor with I2C communication
    Refactor encoder.cpp to use I2C for AS5600 sensor and add setup/loop functions.
2026-09-11 Implemented robot FSM and refined transition logic.
    - Added complete FSM handling for:
    - initialization and calibration
    - track following
    - obstacle avoidance
    - parking search/alignment/reverse/correction
    - finished and safe stop states
    - Integrated vision modules:
    - lane detection
    - pillar detection
    - parking detection
    - Added encoder-based blind parking approach handling.
    - Improved transition conditions:
    - safer obstacle avoidance exit using detection confidence
    - improved curvature-based corner detection
    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
2026-09-11 implemented steering_controller and pid
2026-09-11 edit camera and calibration
2026-09-11 finished communications protocol between Rasp pi5 and esp32
2026-09-11 Revise Mechanics README for clarity and detail 2
    Expanded the README to include detailed mechanical design and assembly instructions for the EVA-505 robot, including chassis specifications, component distribution, and printed parts.
2026-09-11 finished raspberry pi 5 logic
2026-09-11 esp32 implementation
